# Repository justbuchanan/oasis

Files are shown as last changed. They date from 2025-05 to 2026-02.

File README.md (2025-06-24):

   

# Oasis

https://oasis-terrarium.com

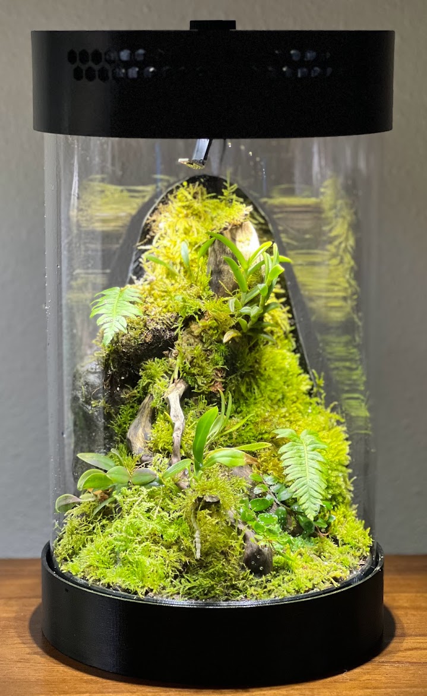
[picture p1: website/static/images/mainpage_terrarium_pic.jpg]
terrarium pic


Oasis is a fully open-source, mostly 3d-printed smart terrarium. It provides the ideal environment for humidity-loving plants like mosses, ferns, orchids, and many others. The design includes:

- [high power LED lighting](https://oasis-terrarium.com/docs/random_notes/#light-intensity)
- a mister for providing plants with water and maintaining high humidity
- fans for airflow
- a temperature/humidity sensor for monitoring environment conditions
- wifi connectivity to allow control and configuration from your phone or computer (see [web interface](https://oasis-terrarium.com/docs/usage_guide/#web-interface))
- outer dimensions: ~8" diameter and ~13" tall

See the website for pictures, build details and more: https://oasis-terrarium.com.

This repository contains full sources for the CAD models (designed with [CadQuery](https://github.com/cadquery/cadquery)), electronics (designed in [KiCad](https://www.kicad.org/)), and software (written in rust using the [esp-rs](https://github.com/esp-rs) libraries).

Most of this project is accessible to the average DIYer with access to a 3d printer, however the electronics portion of the project is a bit more involved. Fully-assembled electronics can be ordered from companies like JLCPCB by uploading the files from this repo, but this can be expensive for small order quantities. Those with the right equipment and experience soldering small parts could order the bare PCBs and components separately, then do their own assembly and soldering.

I'd like to eventually offer the assembled electronics as a kit, but don't have immediate plans for doing so. To express interest in a kit and to subscribe for future updates, please fill out this form: https://forms.gle/WesLJEf8hVrUT4jXA.

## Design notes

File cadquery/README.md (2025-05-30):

# CAD

The 3d-printed models for this project are designed with [CadQuery](https://github.com/CadQuery/cadquery).

See [CQ-editor's installation instructions](https://github.com/CadQuery/CQ-editor/wiki/Installation).

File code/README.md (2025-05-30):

# Oasis Software

The software for this project is divided up into four subdirectories:

- esp32/ - the actual code that runs on the main control board of the terrarium.
- client/ - a command-line client program that runs on linux/macos/windows(?) for controlling the terrarium and querying its state.
- demoserver/ - a server program that runs on your computer (again linux/macos/windows(?)) that allows for developing/testing the web interface without requiring an esp32-based control board.
- terralib/ - shared code that is used by the above three programs.

## ESP32 code

> [!WARNING]
> It is possible to fry the mister circuit on this board by changing the firmware code. The mister circuit expects a ~110kHz 50% duty cycle signal from the esp32. If you instead turn it fully on, it will likely let out the magic smoke within just a few seconds.

### Initial setup

The initial project in the esp32/ directory was setup from a template:

`cargo generate esp-rs/esp-idf-template cargo`

If stuff needs updating, do one or all of the below:

```
rustup update nightly

cargo update

# manually update versions of packages by editing Cargo.toml
```

### Build a single binary

`cargo build --bin oasis` or `cargo build --bin blinky`

### Re-compile when something changes using cargo-watch

`cargo-watch -x 'build --bin oasis'`

### Run oasis program

`cd esp32 && cargo run --release --bin oasis`

### ESP32 OTA Flashing

As of 3/29/25, the oasis program is about 1.7M in size. The total flash size of the ESP32-C3 is 4M. For ota (over-the-air updates) to work, we have to have room for _two_ versions of the app plus the nvs partition (for wifi calibration data), data partition (oasis config file), and phy_init (RF Data, not sure?). Looks like unless we can significantly reduce the size of the oasis app binary, OTA is not an option - there just isn't enough room on the flash memory.

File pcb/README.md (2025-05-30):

# Oasis PCB Design

## KiCad Plugins

This project uses a plugin for laying out components. Some values are defined in /oasis_constants.py, then used in both the CAD model and the PCB layout.

### Component layout plugin

The plugin is located at https://github.com/justbuchanan/kicad_component_layout/blob/versionfix/component_layout_plugin.py and must be copied into Kicad's plugin directory in order to use it.

Usage:

- run pcb/{main, ledboard}/layout.py, which generates a layout.yaml output.

- In Kicad's pcb editor, click "Tools" -> "External Plugins" -> "Layout footprints from layout.yaml".

To edit placement of items, modify `oasis_constants.py` and/or `pcb/{main, ledboard}/layout.py`.

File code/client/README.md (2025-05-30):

# Command-line client

This program connects to the terrarium over the network and allows for:

- scanning for any/all terrariums on the network
- controlling the terrarium (lights, fan, mist)
- configuring the schedule and wifi login for the terrarium
- querying terrarium state

Run `client --help` for full and up-to-date details.

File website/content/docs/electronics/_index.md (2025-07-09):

+++
title = 'Electronics'
weight = 4
+++

# Electronics

## How to get them?

There are essentially three options for obtaining the electronics:

- Order bare PCBs (from OSH Park, JLCPCB, PCBWay) and parts (digikey, mouser, etc) and solder them yourself. This can be a good option if you have experience with SMD soldering.
- Order fully-assembled PCBs from JLCPCB. This can be a good option if you'd prefer not to solder the boards yourself, but it can be expensive for small order quantities.
- [Sign up to buy a kit](/docs/contact/#buying-a-kit) if/when they become available. I don't have any immediate or concrete plans to sell these, but will consider it if there's enough interest.

See the [PCB Ordering Guide](#pcb-ordering-guide) below for more info.

## Design

### Overview

The electronics have a few main tasks:

- power the lights and allow for brightness control ("dimming")
- turn the fans on/off
- drive the mister (this is a somewhat complicated resonant circuit)
- communicate with the temperature+humidity sensor
- wifi
- usb port for programming/debugging

### Microcontroller

Requirements:

- i2c for sensors ([sht30](https://www.digikey.com/en/products/detail/sensirion-ag/SHT30-DIS-B2-5KS/5872250))
- 1 pwm for LED driver
- 1 pwm for mist
- 1 gpio for fans
- wifi

While there are a quite a few microcontrollers that fit the requirements, they vary widely in size and cost. I selected the esp32 due its small size (smaller than a postage stamp), SMD footprint (can be soldered directly to a board), and low cost (~$3).

### LEDs + Driver

I chose [Cree XT-E LEDs](https://downloads.cree-led.com/files/ds/x/XLamp-XTE.pdf) as these are common in the aquarium and terrarium hobbies for building high power lighting and because I have prior experience with them.

A string of LEDs is best powered by a constant-current driver. There are a lot of options here, but I selected the [Meanwell LDD-700LS](https://www.digikey.com/en/products/detail/mean-well-usa-inc/LDD-700LS/7704762) due to its small SMD footprint, dimming control via pwm, and ease of use (no external components required). This driver can provide up to 700mA (hence the 700 in the name), but there are several variants that can provide more or less current.

I chose to go with five LEDs laid out in a circle at the top of the terrarium. The circular spacing gives a more even lighting to the enclosure than we'd get with one LED in the center or several bunched closely together. The choice of five LEDs was somewhat arbitrary.

Cree XT-E LEDs have a forward voltage a little under 3V when current is 700mA (see page 21 of the [datasheet](https://downloads.cree-led.com/files/ds/x/XLamp-XTE.pdf)). With five LEDs in series, this means we need a total voltage of ~15V across the LEDs. The driver input voltage must be around 2v higher than its output voltage, giving us a minimum of ~17v to power the driver.

### Mister

I'm using an ultrasonic mister to provide watering in the terrarium. These are small discs made of a metal+piezo material sandwich with very tiny (~4uM) holes in the center. By applying an alternating voltage across the terminals of the disc, we can cause it to vibrate and "chop up" water into tiny particles that descend into the enclosure. The closer we can drive the disc to its natural resonant frequency (commonly ~110kHz), the faster and more efficiently we can drive it.

I heavily relied on these articles when designing the resonant circuit for driving the mister:

- https://www.edn.com/ultrasonic-mist-maker/.
- https://www.instructables.com/Make-Your-Own-Super-Simple-Ultrasonic-Mist-Maker/

Essentially a mosfet is switched on and off very quickly (~110kHz) causing it to alternate between "charging up" an inductor and dumping that charge across the misting disc. The mosfet is connected to a mosfet gate driver, which receives the 110kHz signal from a pwm output on the microcontroller.

Some mist driver circuits use a dedicated square wave generating IC like a 555 timer to provide the 110kHz signal, however this design uses a pwm output from the microcontroller. This has a couple advantages:

- less components
- the signal frequency can be changed in software to accommodate different misting discs

And one key disadvantage: it is possible to write firmware that outputs an "always on" signal rather than the expected 110kHz square wave, which will cause the misting circuit to let out the magic smoke.

### Voltage Requirements

- LED driver: >17v
- sensors: 2.2v - 5.5v
- esp32: 3.3v
- fans: nominally 24v, but can run at 18v
- mist: >12v

I chose to use an input voltage supply of 18v in order to satisfy the requirements of the higher-voltage devices, then include a voltage regulator to provide 3.3v for the lower-voltage devices. I selected a buck converter from TI and used their WeBench tool to design a regulator circuit. See details [here](https://github.com/justbuchanan/oasis/blob/main/pcb/reference/voltage-circuit-export-from-ti-webench.pdf).

### Thermal Considerations

It turns out that LEDs, even fairly efficient ones like we're using here, produce a lot of heat.

The initial design of the electronics placed all components, including the LEDs and the temperature+humidity sensor on one board. I anticipated that this might have issues with overheating, but the elegance of having everything on one board was too hard to resist, so I stubbornly pushed forward. Below are renders of the initial design:

<!-- Show the front and back renders side-by-side -->
<div class="img-row">
  <div class="img-column2">
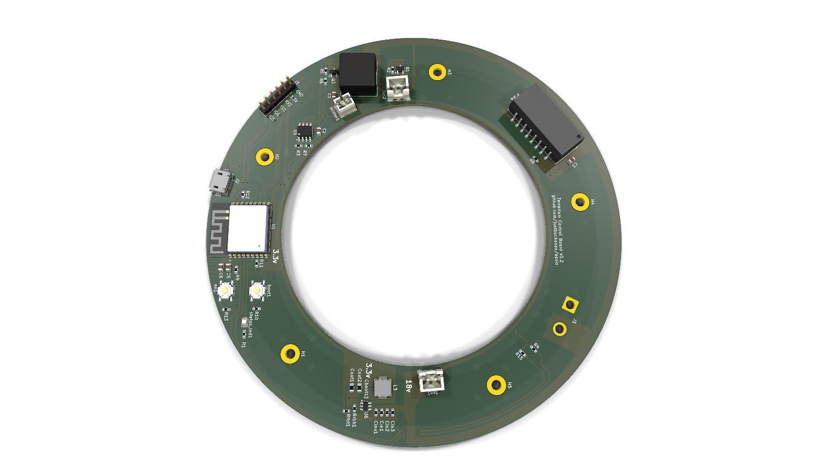
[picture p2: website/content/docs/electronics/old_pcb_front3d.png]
    
    <p>Top View</p>
  </div>
  <div class="img-column2">
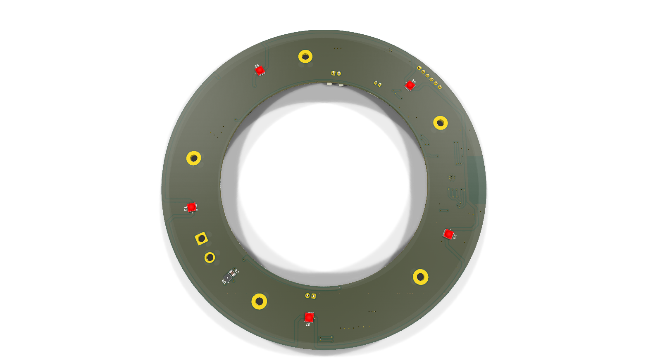
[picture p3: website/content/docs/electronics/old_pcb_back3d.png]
    
    <p>Bottom View</p>
  </div>
</div>

Predictably, the LEDs quickly caused the board to heat up, throwing off the temperature sensor readings and bringing the esp32 close to its operating limits. I attempted to mitigate the overheating by drilling lots of ventilation holes in the 3d-printed top of the enclosure and sticking a dozen small heat sinks to the top of the circuit board. This helped a bit, but not enough. The only way to make this work would be to significantly limit the max LED brightness in firmware, leaving the lighting levels significantly below what I had hoped for the terrarium.

Back to the drawing board! The final design opts to place the LEDs on their own board made out of aluminum to act as a heat sink. Almost everything else is placed on a separate mainboard. The temperature+humidity sensor is on its own board that sits inside the enclosure, thermally isolating it from the heat of the LEDs.

## Mainboard

The mainboard contains:

- a microcontroller with builtin wifi ([esp32-c3](https://www.espressif.com/en/products/socs/esp32-c3))
- led driver
- 18v to 3.3v voltage converter
- ultrasonic mister driver
- fan driver
- usb connector for updating firmware

Find the KiCad design files here: https://github.com/justbuchanan/oasis/tree/main/pcb/main.

### Schematic

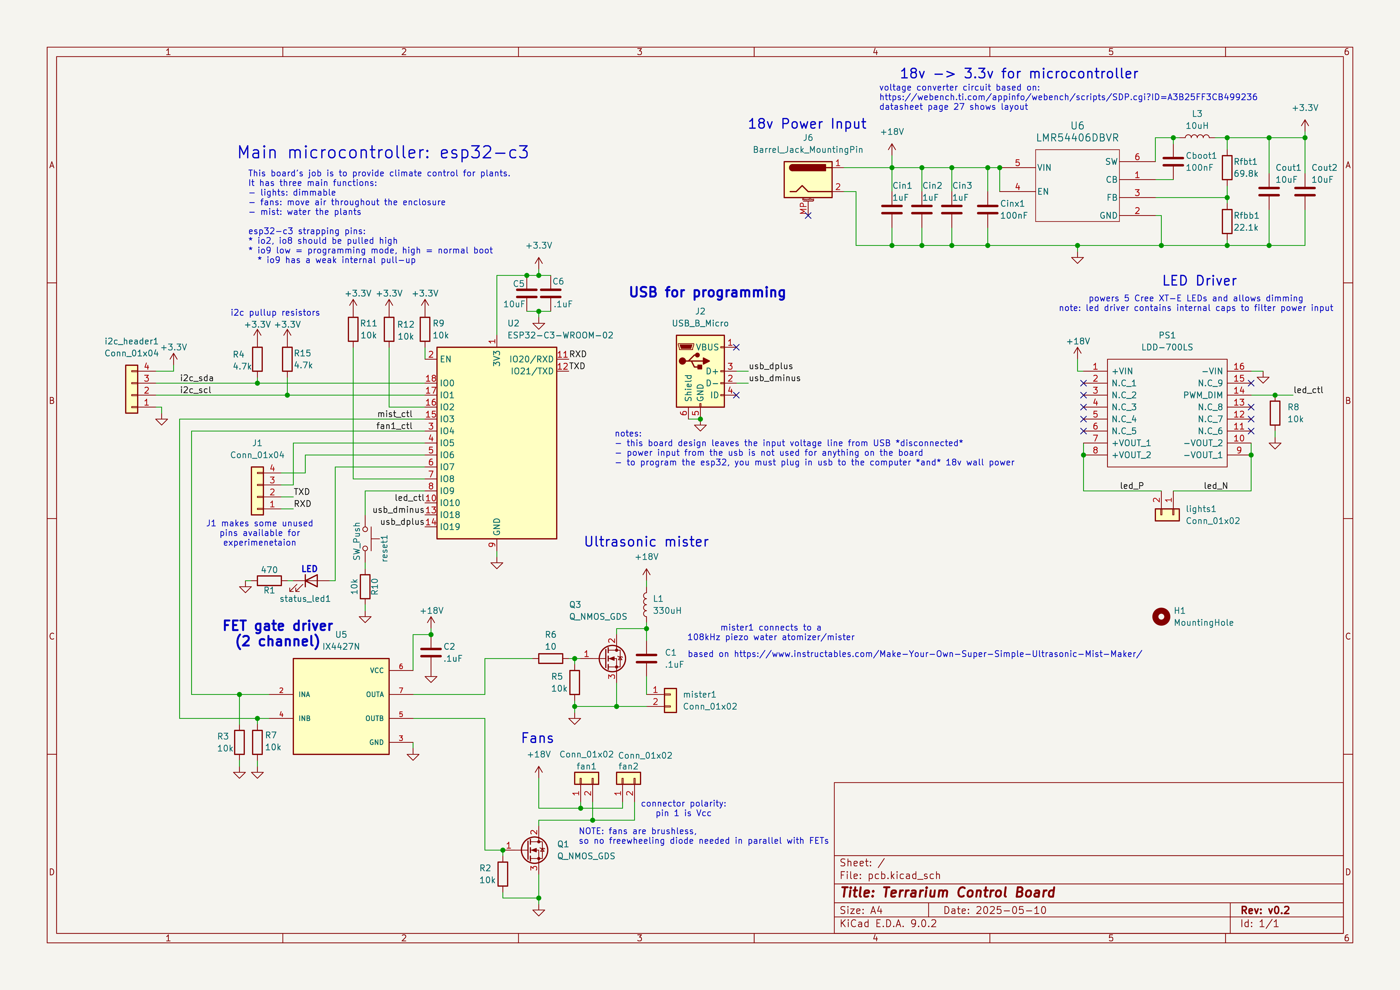
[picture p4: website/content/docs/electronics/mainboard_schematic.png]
schematic


### 3D Renders

<!-- Show the front and back renders side-by-side -->
<div class="img-row">
  <div class="img-column2">
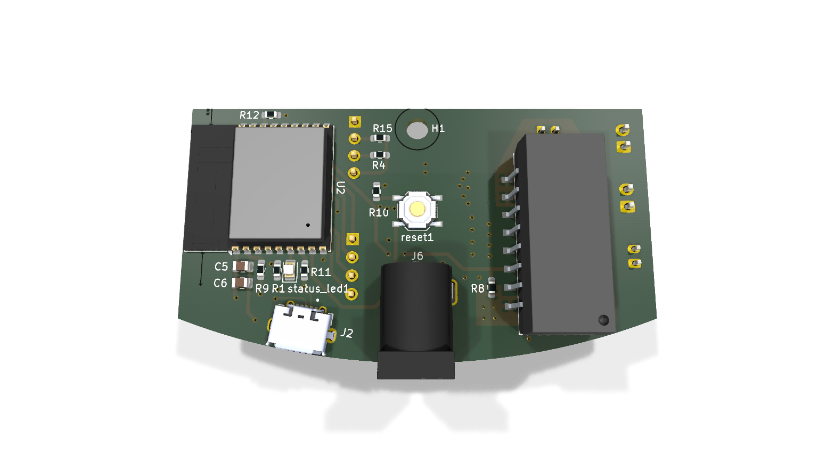
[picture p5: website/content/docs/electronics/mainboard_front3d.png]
    
    <p>Top View</p>
  </div>
  <div class="img-column2">
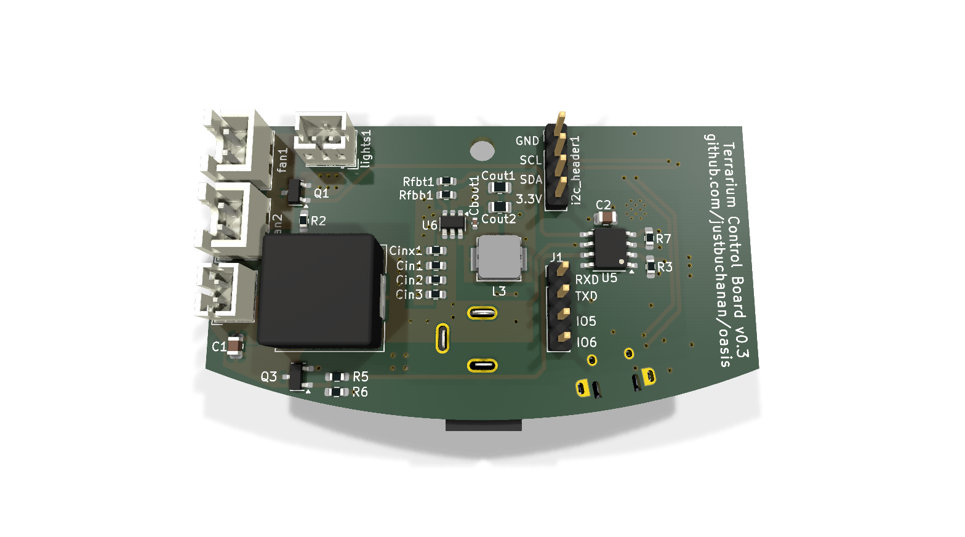
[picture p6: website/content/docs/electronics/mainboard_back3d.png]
    
    <p>Bottom View</p>
  </div>
</div>

## Ledboard

The LED board is very simple - it's 5 LEDs wired in series mounted on an aluminum board to act as a heatsink.

Find the KiCad design files here: https://github.com/justbuchanan/oasis/tree/main/pcb/ledboard.

In order to connect to the mainboard, the ledboard needs a 2-pin JST PH connector (for example https://www.amazon.com/dp/B01DUC1O68) soldered onto it.

### Schematic

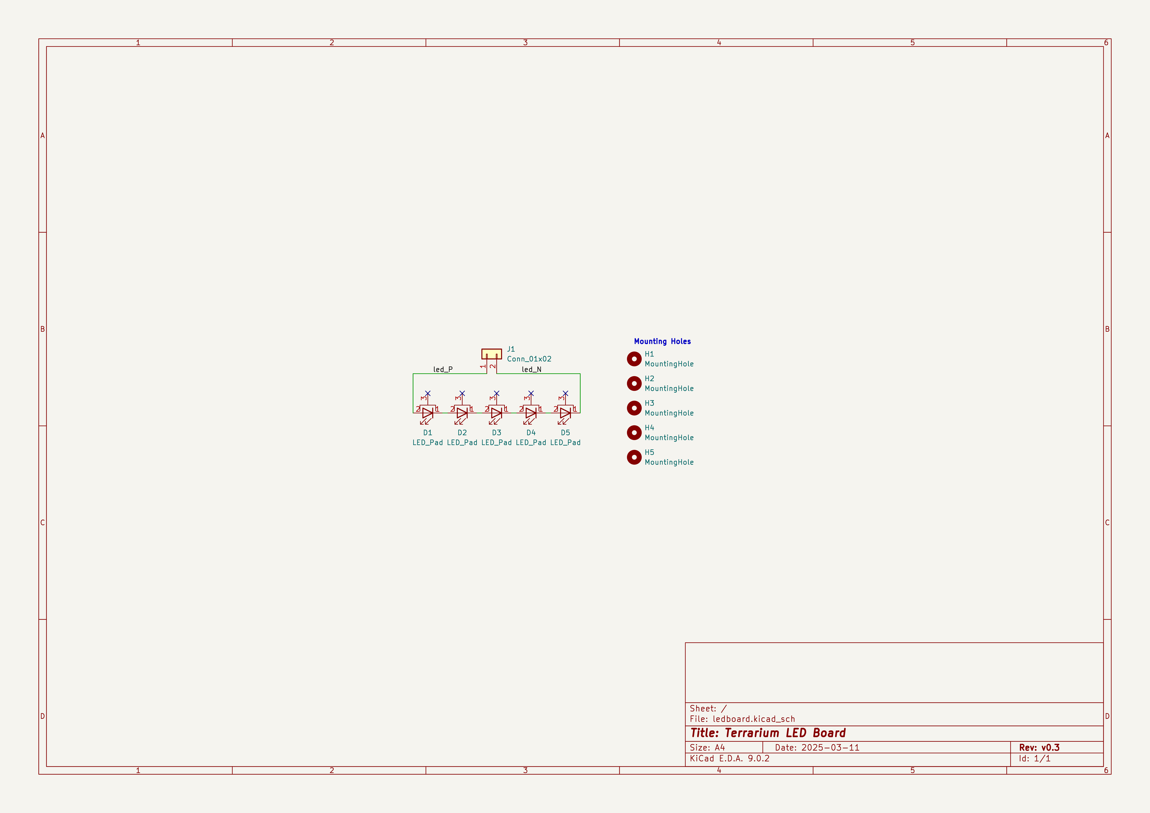
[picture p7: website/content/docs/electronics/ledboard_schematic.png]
schematic


### 3D Render

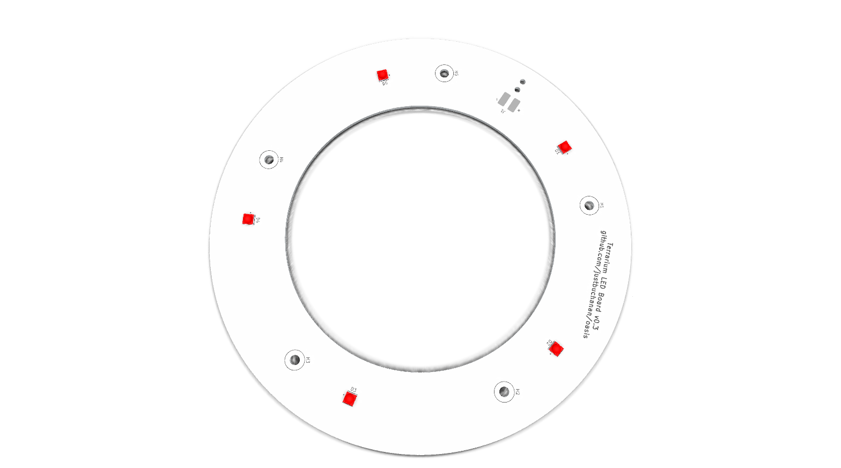
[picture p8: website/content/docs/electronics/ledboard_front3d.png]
front


## SHT30 Sensor Board Wiring

The sht30 sensor board comes without a cable. You'll need to solder a standard 4-pin connector cable in order to plug it into the mainboard.

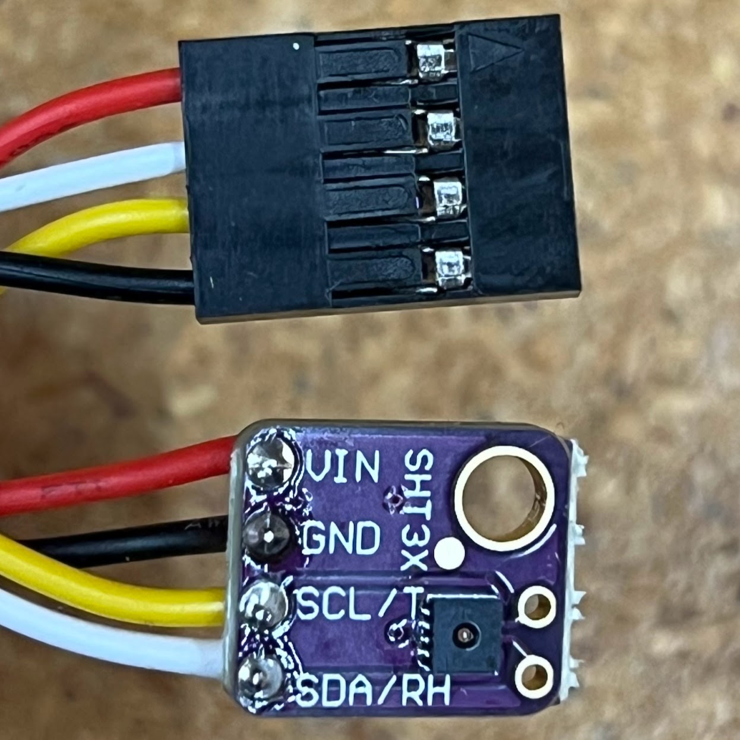
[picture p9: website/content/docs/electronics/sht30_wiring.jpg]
sht30_wiring


## PCB Ordering Guide

There are a lot of options for custom PCB manufacturing. I chose to go with JLCPCB due to low cost, support for board assembly, and extensive component catalog. PCBWay is another good option that also provides assembly services. OSH Park is a good choice for US-based manufacturing, but they don't offer assembly services.

### PCB Production Files

To order custom PCBs, you'll need the production files to send to the manufacturer. If you're ordering bare/un-assembled boards, you'll just need the [gerber files](https://en.wikipedia.org/wiki/Gerber_format) (typically bundled into a `gerbers.zip`), which are essentially vector image files that specify things like where copper traces are located on either side of the board, silkscreen text and images on either side of the board, etc.

If you're looking to order assembled boards, you'll additionally need two more files:

- `bom.csv`: a bill of materials file, which maps from component ids in the board design to specific part numbers in the manufacturer's part catalog
- `pos.csv`/`positions.csv`: file which records the location and orientation of each part

All three production files are generated from the KiCad design files using the [Fabrication-Toolkit plugin](https://github.com/bennymeg/Fabrication-Toolkit). This plugin can be invoked from the KiCad user interface or from the command line. The command line invocation for the plugin is contained in this project's [makefile](https://github.com/justbuchanan/oasis/blob/fbd0d2fceae36f7a195ebd945a816dcebf819d9c/makefile#L142-L147), which you can run with `make pcb`. This will generate the production files for both boards in `build/pcb/main` and `build/pcb/ledboard`. If you make modifications to the board in the KiCad Schematic Editor, run "Tools -> Update PCB From Schematic", then rerun `make pcb` to regenerate the files.

While you can check out the `main` branch of the project in git and use the KiCad files directly, it is recommended to use a tagged release which has been vetted for correctness. It's possible that as the project evolves, changes will be made to the KiCad files that haven't yet been tested.

Tagged releases can be found on the project's [Releases Page on GitHub](https://github.com/justbuchanan/oasis/releases). Alternatively, you can use the design files in the [pcb/fabricated-boards](https://github.com/justbuchanan/oasis/tree/main/pcb/fabricated-boards) directory, which is an archive of all boards ordered to-date.

### Notes On Assembly and Component Selection

JLCPCB has an extensive [catalog of parts](https://jlcpcb.com/parts) they stock in their warehouse(s) and many of the components selected for this project were specifically chosen based on their availability at JLCPCB. There are a couple parts in this design that JLCPCB doesn't stock (including the LED Driver and LEDs) and need to be handled separately. Furthermore, the parts inventory is constantly in flux and it's possible that certain parts that were in stock previously are not in stock when you're placing an order. There are a few options here:

- Skip assembly of those parts, order them separately from somewhere like digikey, then solder them yourself at home.
- Use JLCPCB's pre-order service, which allows you to order almost any part from another supplier. It will take a week or two for the parts to arrive at JLCPCB, after which point you can submit your board order.
- Select a different/equivalent part from JLCPCB's catalog that they do have in stock. This will require you updating the "LCSC Part #" field of the relevant component in KiCad, then regenerating and re-uploading the `bom.csv` file.

#### Overhead Costs and "Basic" vs "Extended" Parts

JLCPCB uses large [pick-and-place machines](https://en.wikipedia.org/wiki/Pick-and-place_machine) for board assembly. These machines have a number of component "reels" attached to them, which hold things like resistors, capacitors, connectors, etc. For commonly-used parts, such as a 1k 0805 resistor, JLCPCB has selected a specific model of the part that they keep loaded up in each of their machines. JLCPCB calls these "Basic Parts" and charges no assembly fee for them since they're already loaded into every machine. When selecting parts, try and find a "Basic" part that fits the bill in order to save money. Any non-"Basic" (i.e. "Extended") parts that require assembly will cost you a $3 setup fee per part. If you're ordering a large number of boards, this is a small cost. If you're only ordering a few, these assembly costs add up.

### JLCPCB Ordering Step-by-Step

Below is a step-by-step guide to placing a board order through JLCPCB. This will focus on the main board, but the steps are largely the same for the LED board. The main differences with the LED board are that the board should be made of aluminum (to act as a heat sink) instead of the standard FR4 and that only one side of the board requires assembly.

1. Go to https://jlcpcb.com and login
1. Upload gerbers.zip
1. (optional) select quantity - default is 5
1. (optional) "Surface Finish": select "LeadFree HASL". Costs like $4 extra on a 5-board order, so why not skip the lead.
1. If you're just ordering bare PCBs, you're done! Finish up the checkout process and place your order.
1. Toggle "PCB Assembly" ON
1. To assembly both sides of the mainboard, change "PCBA Type" from "Economic" to "Standard", then change "Assembly Side" to "Both Sides"
1. (optional) Enable "Confirm Parts Placement" and "Confirm Production file" - it's cheap, so why not have them double-check things?
1. (optional) Adjust assembly quantity. Default is 5, but you could for example order 5 total boards and have only 2 of them assembled.
1. Click the "Next" button
1. Take a quick look over the board images, then click "Next" again
1. Upload "bom.csv" and "positions.csv", then click the "Process" button
1. You're now presented with the bill of materials. If any of the parts say "shortfall" in the right-most column, it means JLCPCB doesn't have those parts. See [Notes on Assembly and Component Selection](#notes-on-assembly-and-component-selection) above.
1. Click "Next" to move on to the assembly review page
1. Click "Next" to move on to the "Quote & Order" Page.
1. Select a "Product Description" from the dropdown. This has tax/tariff/legal implications, but probably doesn't matter much for us. I've been selecting "Other" and typing in "Terrarium for Plants".
1. "Save to Cart" and continue on to checkout
1. See if you can find any relevant coupons: https://jlcpcb.com/coupon-center. There's likely a $15 off coupon for SMT orders over $150. Maybe also a new customer coupon.
1. Finish the checkout process

## PCB Order History

Below are all three circuit board orders I've placed for this project (as of June 2025). All boards were ordered from JLCPCB and include varying levels of assembly (components sourced and soldered by JLCPCB).

### v0.1 all-in-one board - Feb 11, 2025

Single-board design - esp32, leds, sht30 temp/humid sensor, and everything else all on one board.

A lot of the board was assembled by JLC, but the following parts were purchased and assembled separately (in total, probably $17 worth of parts per board):

- led driver
- leds
- sht30 temp/humid sensor
- sht30 bypass capacitor

Files: https://github.com/justbuchanan/oasis/tree/main/pcb/fabricated-boards/v0.2

#### Pricing

note: this price info is what I was charged by JLC, it does not include the components I sourced and assembled myself (mentioned above).

- total: $140
    - merchandise total: $89
    - shipping: $38
    - sales tax: $13

This order was for five boards, so price/board was $28 + ~$17 = ~$45.

### v0.2 ledboard - March 16, 2025

Based on the poor thermal performance of the all-in-one boards, I decided to do a major redesign and put the leds on their own board, made out of solid aluminum. The rest of the electronics are on their own board.

This order is for 5x 1.6mm thick aluminum boards for the leds. Price/board = $6.84. This price doesn't include the 5 Cree XT-E LEDs or the connector cable soldered on.

Files: https://github.com/justbuchanan/oasis/tree/main/pcb/fabricated-boards/ledboard-v0.3

#### Pricing

- total: $35
    - merchandise total: $14
    - shipping: $18
    - sales tax: $3

### v0.2 mainboard - March 21, 2025

Files: https://github.com/justbuchanan/oasis/tree/main/pcb/fabricated-boards/mainboard-v0.3

5 Control boards. Fully assembled except the 2 4-pin headers. Price/board = $40.6.

- total: $203
    - merchandise total: $153
    - shipping: $29
    - sales tax: $21

## Power Consumption

Power consumption of the electronics was measured using a bench power supply set to 18V. Here are the results:

| Configuration | Current Draw (amps) |
| --- | --- |
| Microcontroller plugged in, everything (mist, fans, lights) off | 0.01-0.03 |
| LEDs 100% on | 0.61 |
| Fans on | 0.09 |
| Mister on, water present | 0.05 |
| Mister on, no water present | 0.03 |
| Everything on (mister, fans, LEDs @ 100%), water present | 0.72 |

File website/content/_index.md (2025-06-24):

+++
title = 'About'
weight = 1
+++

# Oasis

Oasis is a fully open-source, mostly 3d-printed smart terrarium.

{{< video src="docs/video.mp4" width=100% controls="yes" autoplay="true" >}}

Features include:

- [high-power LED lighting](/docs/random_notes/#light-intensity)
- a built-in water tank and mister to provide plants with water and maintain high humidity
- fans for airflow
- a temperature+humidity sensor for monitoring environment conditions
- wifi connectivity to allow control and configuration from your phone or computer (see [web interface](/docs/usage_guide/#web-interface))
- outer dimensions: ~8" diameter and ~13" tall

This project is fully open-source, meaning that the designs for the 3d printed parts, electronics schematics, and software are available to download and modify. Find them on GitHub: https://github.com/justbuchanan/oasis.

This website contains a detailed [build guide](/docs/build_guide), bill of materials, and other notes on the project.

Most of this project is accessible to the average DIYer with access to a 3d printer, however the electronics portion of the project is a bit more involved. See the [Electronics page](/docs/electronics) for more details.

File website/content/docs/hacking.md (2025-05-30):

+++
title = 'Hacking'
weight = 6
+++

# Hacking

This is an open-source project built on open-source tools. It uses [KiCad](https://www.kicad.org/) for electronics design, [CadQuery](https://github.com/CadQuery/cadquery) for 3d-modeling, and [rust](https://www.rust-lang.org/) for the software.

## Code

See the readme for more info: https://github.com/justbuchanan/oasis/blob/main/code/README.md

## CAD models

The CAD models for this project are designed in [CadQuery](https://github.com/cadquery/cadquery), which uses python for part design. This project's [requirements.txt file](https://github.com/justbuchanan/oasis/blob/main/requirements.txt) contains the relevant python dependencies, but you may need to consult the CadQuery documentation for further installation instructions.

Note that while the python environment is _mostly_ for working with the CAD models, there are some optional python dependencies needed for working with the KiCad electronics designs. These include the [Fabrication-Toolkit plugin](https://github.com/bennymeg/Fabrication-Toolkit) for exporting manufacturing files for JLC PCB and the [component layout plugin](https://github.com/justbuchanan/kicad_component_layout).

### Python Environment Setup

#### Initial setup (do once)

```sh
cd <this project>
mkdir -p pyvenv
python -m venv ./pyvenv --system-site-packages
source ./pyvenv/bin/activate
pip install -r requirements.txt
```

#### Environment (do every time)

Run this in your shell before you do anything related to python, including running `make`.

```sh
cd <this project>
source ./pyvenv/bin/activate
```

## Command-Line Client

This project comes with a command-line client that can:

- configure wifi credentials
- set the terrarium's schedule (lights, fans, mister)
- query the terrarium's state (sensors, light level, etc)
- control lights, fans, mister
- scan the network for online terrariums

Source code is at https://github.com/justbuchanan/oasis/tree/main/code/client.

For full documentation, build the client and run `oasis --help`.

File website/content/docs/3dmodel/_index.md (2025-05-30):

+++
title = '3D Model'
weight = 5
+++

<script type="module" src="https://ajax.googleapis.com/ajax/libs/model-viewer/4.0.0/model-viewer.min.js"></script>

<model-viewer id="model"
              src="oasis.glb"
              alt="Oasis Terrarium 3D Model"
              field-of-view="8deg"
              camera-orbit="90deg"
              camera-controls
              touch-action='pan-y'
              ar
              style="width: 100%; height: 1000px;">
</model-viewer>

Controls:

- Scroll to zoom
- left-click drag to rotate
- right-click drag to pan

<script>
const modelViewer = document.getElementById('model');

modelViewer.addEventListener('load', () => {
    console.log("played");
  modelViewer.play({repetitions: 1});
});
</script>

<!-- Creating the glb file:
1. export from cadquery by running `make build/cadquery/oasis.glb`
2. open blender
3. import oasis.glb
4. Follow this youtube video to create the exploding effect: https://www.youtube.com/watch?v=IC0-9b0Rv2g&ab_channel=GeorgeKayesi
    4.1. create an empty shape (cube or axes) and move it off to the side of the terrarium model. Scale up the cube a bit (maybe 50x) to make it easily visible. Set its z position to zero - that way it's easy to get it back to its start position later.
    4.2. select the tube/walls, then add a "copy position" constraint.
        - only z axis should be applied (uncheck x and 7)
        - check the "offset" box
    4.3. select every shape that isn't the tube/walls. then select the walls (this must be selected last). then copy the "copy position" constraint to selected objects.
        - note: don't select visually and don't select them direct in the tree view on the right side. you need to individually select each part (an extra level deep in the tree, has an upside-down triangle next to it)
5. drag the empty cube upwards until the top-most item in the assembly is where you want it to be.
6. for every part, adjust the copy position influence down so the part is where you want it.
6. TODO: figure out keyframe 1 and keyframe 100
7. export the finished product. this is mostly just the same glb as before, but with an added animation.
    - animation checkbox: checked
    - animation mode: active actions merged
        - note that the default options export a separate animation for each individual object in the assembly. model-viewer works best (or at all?) with one single animation.
        - bake animations box: checked

Glass:
On the right side, click the "Render Properties" Menu
    - Render Engine: set to "Cycles"

Click on acrylic walls, then go to material menu
- Use Principled BSDF
- color should be white
- set Roughness to 0
- IOR set to 1.45
- Transmission: set to 1.0 (or maybe just a hair less?)

Plastic material:
    - Roughness factor: 1.0 -> 0.75
    - metallic factor: 1.0 -> 0.5
 -->

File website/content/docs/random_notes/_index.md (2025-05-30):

+++
title = 'Random Notes'
weight = 7
+++

# Random Notes

## Light Intensity

I used the [Photone App for iOS](https://apps.apple.com/us/app/photone-grow-light-meter/id1450079523) to take some lighting measurements. An actual PAR meter would give more accurate measurements, but those are expensive and I already spent all my money on tariffs importing custom electronics from China.

These measurements were taken with an iPhone sitting at the _bottom_ of the terrarium. You will get higher PAR values higher up in the enclosure.

The LEDs are powerful and, due to thermal considerations, the LED driver is limited to 80% power in the firmware (see code [here](https://github.com/justbuchanan/oasis/blob/main/code/esp32/src/terrarium/real_terrarium.rs)). The below percentage values are what you would set in the terrarium's control interface, so for example, the 80% value below actually means 80%\*80%=64% of what the LEDs/driver are capable of.

This test was done with CREE XT-E 5700k LEDs. Results may vary for different color temperatures.

| Light % | PAR (umol/m^2/s) |
| --- | --- |
| 80% | 325 |
| 100% | 414 |

### How much light do plants want?

Here are a couple pages I found helpful:

- https://www.neherpetoculture.com/vivariumlighting101
- https://herebutnot.com/light-recommendations-ppfd-par-for-orchids-and-houseplants/

tl;dr: these LEDs are very bright, don't set them too high.

## Ideas for Future Improvement

The terrarium in its current state works well, but there's room for improvement. Below are a few ideas for a future version of the design:

- The terrarium should be able to detect when the water tank is empty. There are a few options for how to implement this:
    - Add a sensor inside the tank. A float sensor or capacitive sensor could work well.
    - Measure mister current draw. The mister circuit draws almost 2x as much current when water is present.
    - Measure humidity before and after running the mister and see if it increased. It should be possible to do this in software using the current hardware, but can be tricky.
- Increase airflow from fans. While the fans are not particularly powerful to begin with, they are somewhat limited in the current design by the size of the inflow and outflow paths built into the 3d printed parts. This is in turn limited by the size of the led board. If the led board is made smaller in a future version, there could be room to make the air inlet larger.
- The mister/mount/screws stick out below the bottom of the Top. Ideally, the top should be able to set down (face down) on a table and not have anything touch.
- The cord running down the back is ugly. I don't really see a way around this, but adding a cable clip to the bottom piece might help at least tidy it up a bit.
- Make the water tank bigger. Right now there's some "wasted" space that could be used to have the terrarium hold more water.

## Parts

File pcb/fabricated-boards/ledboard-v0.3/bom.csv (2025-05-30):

Designator | Footprint | Quantity | Value | LCSC Part #
D1, D2, D3, D4, D5 | LED_XTEAWT-00-0000-000000F51 | 5 | LED_Pad | C9900048586
J1 | wire2board_smt_justin | 1 | Conn_01x02 | C295747

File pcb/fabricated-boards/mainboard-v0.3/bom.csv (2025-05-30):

Designator | Footprint | Quantity | Value | LCSC Part #
C1, C2, C6 | 0805 | 3 | .1uF | C28233
C5 | 0805 | 1 | 10uF | C15850
CBOOT1 | 0402 | 1 | 100nF | C1525
CIN1, CIN2, CIN3 | 0603 | 3 | 1uF | C15849
CINX1 | 0603 | 1 | 100nF | C14663
COUT1, COUT2 | 0805 | 2 | 10uF | C440198
FAN1, FAN2 | JST_XH_B2B-XH-A_1x02_P2.50mm_Vertical | 2 | Conn_01x02 | C158012
I2C_HEADER1, J1 | PinHeader_1x04_P2.54mm_Vertical | 2 | Conn_01x04
J2 | MOLEX_47590-0001 | 1 | USB_B_Micro | C136001
J6 | DC-IN-TH_XDJK-0051-025_JLC_C7498153 | 1 | Barrel_Jack_MountingPin | C7498153
L1 | L_SXN_SMDRI127 | 1 | 330uH | C10152
L3 | L_Vishay_IHLP-2020 | 1 | 10uH | C844983
LIGHTS1, MISTER1 | JST_PH_B2B-PH-K_1x02_P2.00mm_Vertical | 2 | Conn_01x02 | C131337
PS1 | LDD-700LS-SOP254P1280X930-16N | 1 | LDD-700LS | C17353291
Q1, Q3 | SOT-23-3-pinswapped-mosfet | 2 | Q_NMOS_GDS | C7420571
R1 | 0603 | 1 | 470 | C23179
R10, R11, R12, R2, R3, R5, R7, R8, R9 | 0603 | 9 | 10k | C25804
R15, R4 | 0603 | 2 | 4.7k | C23162
R6 | 0603 | 1 | 10 | C22859
RESET1 | SW_Push_1P1T_XKB_TS-1187A | 1 | SW_Push | C318884
RFBB1 | 0603 | 1 | 22.1k | C844759
RFBT1 | 0603 | 1 | 69.8k | C861526
STATUS_LED1 | 0805 | 1 | LED | C2297
U2 | ESP32-C3-WROOM-02 | 1 | ESP32-C3-WROOM-02
U5 | SOIC-8-1EP_3.9x4.9mm_P1.27mm_EP2.29x3mm | 1 | IX4427N | C171845
U6 | SOT-23-6 | 1 | LMR54406DBVR | C3193129

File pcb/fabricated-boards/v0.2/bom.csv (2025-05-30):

Designator | Footprint | Quantity | Value | LCSC Part #
BOOT1, EN1 | SW_Push_1P1T_XKB_TS-1187A | 2 | SW_Push | C318884
C1, C2, C3, C4, C6 | 0805 | 5 | .1uF | C28233
C5 | 0805 | 1 | 10uF | C15850
CBOOT1 | 0402 | 1 | 100nF | C1525
CIN1, CIN2, CIN3 | 0603 | 3 | 1uF | C15849
CINX1 | 0603 | 1 | 100nF | C14663
COUT1, COUT2 | 0805 | 2 | 10uF | C440198
D1, D2, D3, D4, D5 | LED_XTEAWT-00-0000-000000F51 | 5 | LED_Pad
FAN1, FAN2 | JST_XH_B2B-XH-A_1x02_P2.50mm_Vertical | 2 | Conn_01x02 | C158012
J2 | USB_Micro-B_Amphenol_10104110_Horizontal | 1 | USB_B_Micro | C428496
J3 | PinHeader_1x06_P2.54mm_Vertical | 1 | Conn_01x06 | C7430362
L1 | L_SXN_SMDRI127 | 1 | 330uH | C10152
L3 | L_Vishay_IHLP-2020 | 1 | 10uH | C844983
MISTER1 | JST_PH_B2B-PH-K_1x02_P2.00mm_Vertical | 1 | Conn_01x02 | C5251182
PS1 | LDD-700LS-SOP254P1280X930-16N | 1 | LDD-700LS | C17353291
Q1, Q3 | SOT-23-3 | 2 | Q_NMOS_GDS | C7420571
R1 | 0603 | 1 | 470 | C23179
R10, R11, R12, R2, R3, R5, R7, R8, R9 | 0603 | 9 | 10k | C25804
R13 | 0603 | 1 | 1k | C21190
R15, R4 | 0603 | 2 | 4.7k | C23162
R6 | 0603 | 1 | 10 | C22859
RFBB1 | 0603 | 1 | 22.1k | C844504
RFBT1 | 0603 | 1 | 69.8k | C137689
STATUS_LED1 | 0805 | 1 | LED | C2297
U1 | MODULE_ESP32-C3-WROOM-02-H4 | 1 | ESP32-C3-WROOM-02-N4 | C2934560
U4 | Sensirion_DFN-8-1EP_2.5x2.5mm_P0.5mm_EP1.1x1.7mm | 1 | SHT30-DIS | C77361
U5 | SOIC-8-1EP_3.9x4.9mm_P1.27mm_EP2.29x3mm | 1 | IX4427N | C171845
U6 | SOT-23-6 | 1 | LMR54406DBVR | C5219316

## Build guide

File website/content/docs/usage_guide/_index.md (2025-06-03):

+++
title = 'Usage Guide'
weight = 3
+++

# Usage Guide

You're terrarium's all assembled, what's next?

## A Note on WiFi / Internet Access

The terrarium is designed to connect to your home wifi network for two reasons.

The most obvious is so that it can be configured, controlled, and monitored from your phone or computer.

The less obvious reason is that the terrarium has no way of knowing what time it is when it first turns on. In order to determine the current time, it asks the internet (see [ntp on wikipedia](https://en.wikipedia.org/wiki/Network_Time_Protocol)). This is the only communication the terrarium does with the internet. If you're familiar with software, you're welcome to review the [code](https://github.com/justbuchanan/oasis/tree/main/code) and verify for yourself :)

> [!NOTE]+ Note
> It would be possible to change the software so that you can manually tell the terrarium what time it is, making it unnecessary for it to connect to the internet. The downside is that you would have to do this every time you unplug it or there's a power outage.

> [!NOTE]+ Note
> It would be possible to add a battery and a time-keeping circuit to the control board so that once configured, the terrarium wouldn't need to use the internet to determine the current time. The downside is that this would increase the cost and complexity of the device. Because WiFi connectivity is already required to control the terrarium from your phone/computer, this probably isn't worth it.

## Firmware Installation / Updates

Before you can begin using the terrarium, you'll need to install the firmware on the mainboard. See the [readme](https://github.com/justbuchanan/oasis/tree/main/code#run-oasis-program) for more info.

## Initial Setup

After plugging in the power supply, Oasis will start up and begin broadcasting its own wifi network named something like `oasis-1234` (with a random 4-digit number). Connect to this network, then open your web browser and navigate to `http://oasis.local` to connect to the terrarium.

In the "Settings" section at the bottom, you can enter the name and password for your wifi network and optionally change the "hostname" of the terrarium. The default hostname makes the terrarium accessible at "http://oasis.local", but you can change it to whatever (valid) name you'd like. Once you've entered the wifi information, click the "submit" button. This will cause the terrarium to restart and attempt to connect to your wifi network.

You can now connect your phone/computer back to your main wifi network and browse to the hostname of the terrarium (again the default is "http://oasis.local"). Assuming everything worked, you're all setup!

If the terrarium was unable to connect to the network, it will revert back to broadcasting its own network (something like "oasis-1234"), allowing you to re-enter the wifi password, etc, and try again.

## Web Interface

Here's a screenshot:

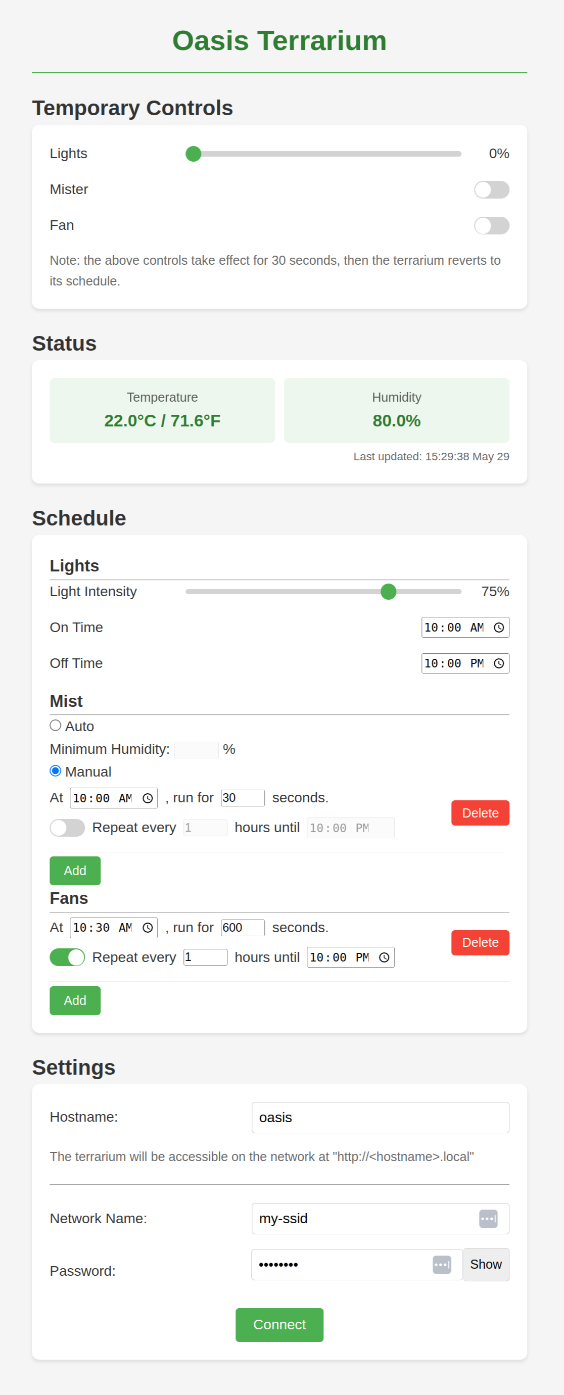
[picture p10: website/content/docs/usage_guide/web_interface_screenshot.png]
web_interface_screenshot


### Schedule

Oasis defaults to having the lights on at 70% power from 10am to 10pm, but you can adjust this however you'd like based on your selection of plants and personal preferences.

> [!NOTE]
> The LED lighting in this design is fairly powerful and it's likely that 100% power is too high for many plants. You may need to experiment to determine what the light intensity should be for your setup.

Like the lighting, the mister and fans can be scheduled to run throughout the day.

### Temporary Controls

In addition to the automated schedule, the lights, mister, and fans can be controlled on a temporary basis using the controls at the top of the web interface.

From past experience, I've learned that it's not a good idea to have a button that says "turn the mist on until I turn it off again" because at some point you will press the button and walk away and forget about it. When you return later, the water tank will be empty and your plants will be drenched. For this reason, the temporary controls all take effect for 30 seconds, before reverting back to the terrarium's configured schedule.

## Filling the Water Tank

To access the water tank, unscrew the plug on the top. Fill the tank until the water level is just a bit below the o-ring. I'd recommend using a funnel or a squirt bottle (something like [this](https://www.amazon.com/dp/B07DB1HCKP)) to fill the tank because otherwise it is very easy to spill water through the ventilation holes into the top piece of the terrarium. Perhaps having the ventilation holes so close to the water fillup port is a design flaw, but this is the current state of the design.

### Distilled or RO Water is Recommended

## Adjusting the Mister

too tight = reduced mist output
too loose = water leaking around the o-ring/mister

## Plants!

I'll refrain from including much information on design and planting here because there are a lot of good resources online that cover this in depth.

When it comes to plants, the main thing to keep in mind is that the terrarium is a high-humidity environment. Plants like succulents and cacti will not do well here. Plants like mosses, ferns, miniature orchids, and many others will do well.

Another consideration is size - select plants that won't quickly outgrow the limited space available.

By design, the side walls of the terrarium are easy to remove and put back again. This makes it easy to clean the walls and to get access to your plants for trimming, rearranging, etc. You may opt to build your terrarium in a way that the walls will stay fixed - maybe you want to lean sticks, rocks, dirt, etc against the walls to create a structured layout, and that's ok! Just be aware that you may be unable to remove the walls later. If you go this route, consider glueing the walls into the bottom piece for added strength.

## Hard Reset

The terrarium includes a hard reset button at the top that can be pressed using a standard paperclip. You should never actually have to use this - it's there as a failsafe in case there's an issue with the software and you want to reset the configuration to "factory default".

If you're having issues with connecting to the terrarium, first try rebooting it. There is no reboot button - just unplug the power cable, then plug it back in.

If you do need to use the hard reset, press the button down for ~5 seconds. The terrarium will start flashing its lights slowly for those 5 seconds, then flash them quickly to let you know the reset was registered. It will then delete its configuration (wifi information, schedule, etc) and reboot. Once it restarts, you can follow the [Initial Setup](#initial-setup) instructions to reconfigure it.

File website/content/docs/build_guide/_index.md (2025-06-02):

+++
title = 'Build Guide'
weight = 2
+++

# Oasis Build Guide

Below is a step-by-step guide on building the terrarium.

## Bill of Materials

| Item | Quantity | Source 1 | Source 2 | Notes |
| --- | --- | --- | --- | --- |
| Carclo 10140 LED Optics | 5 | [amazon](https://www.amazon.com/dp/B00LWU1G78) ($8.50 for 6) | [LEDsupply](https://www.ledsupply.com/led-optics/10140-carclo-lens-frosted-wide-spot-led-optic) ($1.60 each) | Other carclo 20mm optics will work. Different options include frosted/not-frosted and different illumination patterns / angles. |
| O rings (18mm OD 12mm ID 3mm Width) | 2 | [amazon](https://www.amazon.com/dp/B08HHDG9SX) ($9 for 20) | | |
| Acrylic Sheet - 12" x 24" x 1/32" thick | 1 | [amazon](https://www.amazon.com/dp/B08SW564X3?=) ($10) | | |
| Acrylic Cement | just a bit | [amazon](https://www.amazon.com/dp/B00R5NYM7M) ($18 for 5oz tube)  | | |
| 24v blower fan 30x30x10mm | 2 | [amazon](https://www.amazon.com/dp/B08MKLDGQR) ($10 for 2) | [amazon](https://www.amazon.com/dp/B0CGTRNFZV) ($12 for 6) | |
| Temperature/Humidity Sensor Board | 1 | [amazon](https://www.amazon.com/dp/B0CN32WXJY) ($13 for 3) | | This board needs a cable soldered to it. See the [Electronics Page](/docs/electronics/#sht30-sensor-board-wiring) for details.  |
| 18V 1A+ Power Supply | 1 | [amazon](https://www.amazon.com/dp/B0C7158MH4) ($10) | [digikey](https://www.digikey.com/en/products/detail/globtek-inc/WR9HH1000LCP-F-R6B/10187589) ($5.87) | |
| Ultrasonic Mister Disc | 1 | [amazon](https://www.amazon.com/dp/B0C1C79BH3) ($9 for 3) | | These come with their own circuit boards, which aren't needed because the driver circuit is built into the oasis mainboard. |
| Epoxy Resin | about 80 grams | [amazon](https://www.amazon.com/dp/B07YCVVYFK) ($21 for 960g/34oz) | | |
| Grease | just a bit | [amazon](https://www.amazon.com/dp/B004X70LZA) ($6 for 8oz) | | |
| M3x20mm Socket Cap Screws | 2 | | | |
| M3x8mm Socket Cap Screws | 4 | | | |

### 3D-Printed Parts

| Name          |
| ------------- |
| Top           |
| Bottom        |
| Underplate    |
| Mister Cover  |
| Top Plug      |
| Sensor Basket |

See https://www.printables.com/model/1315117-oasis-smart-terrarium.

### Custom Electronics

This project requires two custom electronics boards: a mainboard and an LED board. See the [Electronics page](/docs/electronics) for more info.

## 3D Printing

This project requires a number of 3d-printed parts. Most of them need to handle high humidity and/or direct contact with water, so it's important to use a material that can handle that. PLA, for example, is a poor choice. I used PETG for this, but ABS and some other plastics should work well.

Model files (STL/STEP) can be downloaded from [printables.com](https://www.printables.com/model/1315117-oasis-smart-terrarium) or [GitHub](https://github.com/justbuchanan/oasis/releases/tag/v1).

### Supports

The only 3d-printed part that needs supports during printing is the sensor basket, which has two small tabs at the top. Tree supports in PrusaSlicer worked well here. All other parts for this project are designed to not need supports.

### PETG Settings

I used a Prusa i3 MK3S+ to print parts in PETG for this project. I initially had some trouble with my first layer of printing, so I've included the settings changes to PrusaSlicer I used below. These print settings are not specific to this project, but may be helpful. My main issue was lack of bed adhesion, so I slowed down the first layer significantly.

- Layers and Perimeters > Quality > Extra perimeters if needed: no -> yes
- Infill density: 15% -> 25%
- Speed > Modifiers > First layer speed: 20mm/s -> 10mm/s
- Speed > Acceleration Control > First layer: 800mm/s^2 -> 600mm/s^2
- Filaments > Temperature > Bed > First Layer: 85C -> 90C

### Waterproofing

There are two printed parts that need to be able to hold water without leaking. While it's _possible_ to get these waterproof straight off of the printer by tweaking your print settings, this is difficult and unlikely to work consistently. I used a low-viscosity epoxy to waterproof the bottom piece as well as the water tank in the top piece.

> [!NOTE]+ Note
> I initially tried to use polyurethane for waterproofing, but found that after two coats, the water tank still leaked. I was eventually able to achieve waterproofing after four coats. Epoxy has consistently worked after just one application.

#### Waterproofing Step-By-Step Guide

Before you begin, you will need the following:

- epoxy
- 3d-printed top piece
- 3d-printed bottom piece
- 3d-printed top plug
- o-ring
- paper towels
- optional: solo cup(s), small funnel, gloves, q-tips, weigh scale

Detailed instructions (with pictures!) follow, but the **tl;dr is: fill the water tank in the top piece with epoxy and slosh it around to fully coat the interior. Drain the excess epoxy into the bottom piece and slosh that around to fully coat its interior. After curing, the pieces will be waterproof.**

Start by mixing up about 80 grams of epoxy (40g part A, 40g part B). This is by no means an exact amount you need to match, but should give you an idea of how much is needed. Follow the instructions that come with your epoxy and be sure to mix well.

Place the o-ring and then the top plug into the top piece.

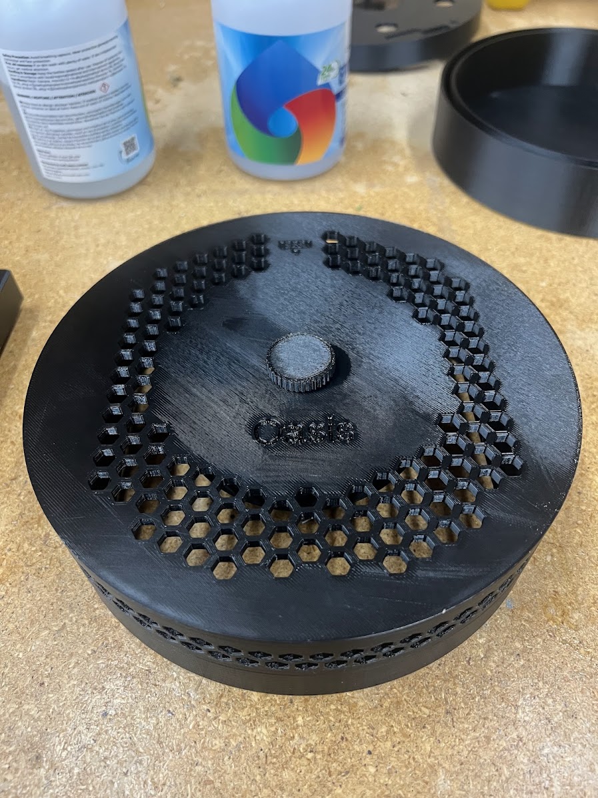
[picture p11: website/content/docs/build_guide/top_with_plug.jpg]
top_with_plug


Place the top piece on a table upside-down, then pour the epoxy into the water tank.

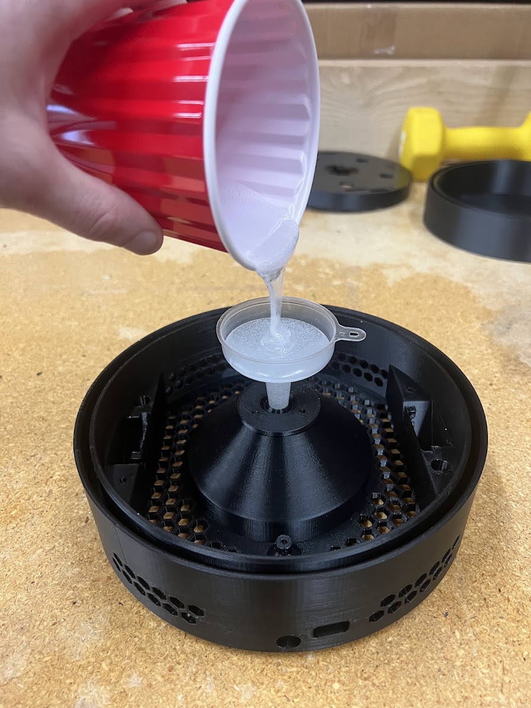
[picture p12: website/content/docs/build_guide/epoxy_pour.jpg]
epoxy_pour


Once the water tank is filled, remove the funnel and cover the hole with a piece of tape or your thumb. Now you'll need to slowly rotate the top piece around to ensure that the epoxy flows around inside the water tank and covers all interior surfaces. Take your time with this and make sure to tilt the piece at every possible angle. It's much better to spend a few extra minutes here making the sure the epoxy covers everything than to later find out that the water tank isn't waterproof. This process should take several minutes.

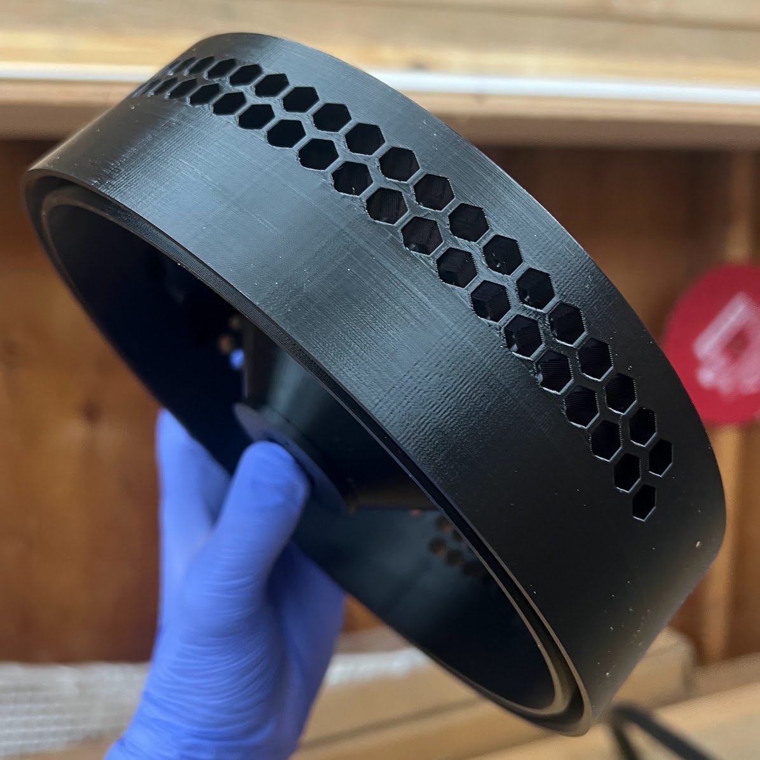
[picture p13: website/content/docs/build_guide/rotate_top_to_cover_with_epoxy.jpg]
rotate_top_to_cover_with_epoxy


Once you've thoroughly coated the interior of the water tank, set the top piece on top of the bottom piece and allow all the excess epoxy to drain out.

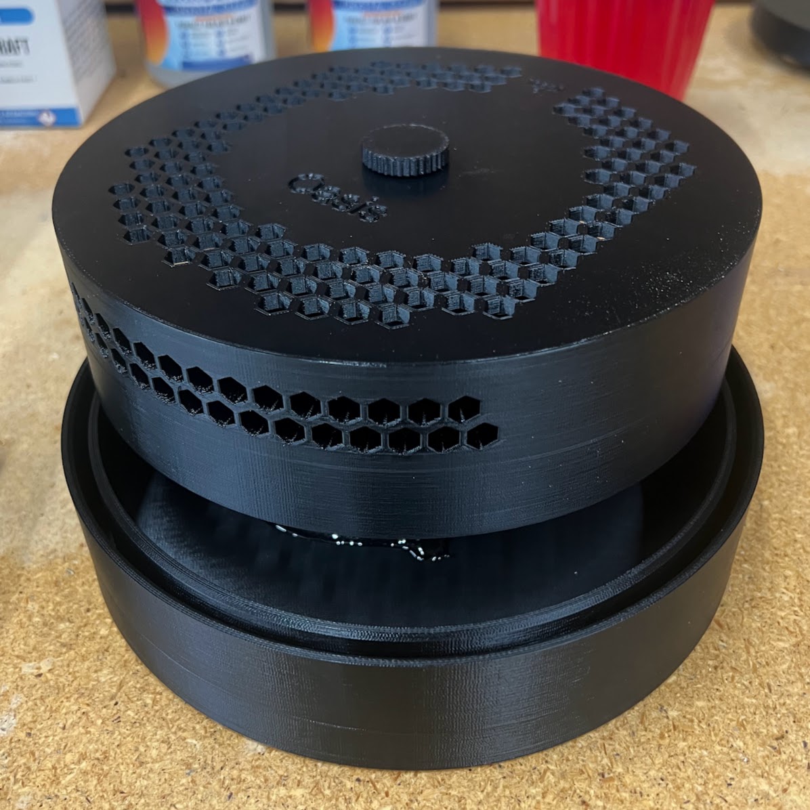
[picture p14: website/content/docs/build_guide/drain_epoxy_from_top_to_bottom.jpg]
drain_epoxy_from_top_to_bottom


Remove the plug and o-ring from the top and wipe them clean of epoxy using a paper towel.

It should take about 5-10 minutes for most of the epoxy to drain from the top piece into the bottom piece. Once that's done, smear a tiny amount of epoxy in the o-ring well of the top piece. Use just enough to coat the surface, but not enough that the o-ring will not fit later. Use a paper towel to wipe up the surface and clean up any excess.

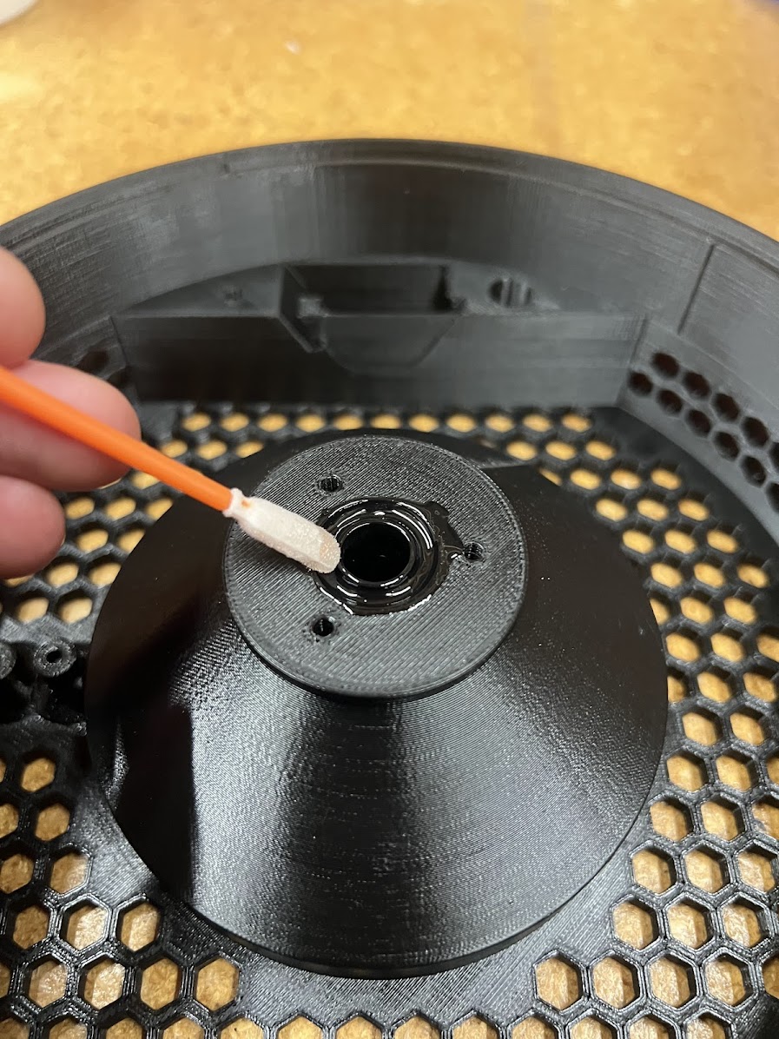
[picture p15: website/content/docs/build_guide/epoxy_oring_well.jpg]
epoxy_oring_well


Set the top piece somewhere (with epoxy entry/exit hole facing down) to continue draining any remaining excess epoxy and to cure. It's worth checking on this an hour or two later and wiping down any epoxy drips that may have formed.

Next step is to coat the interior of the bottom piece with epoxy. Slowly tilt and rotate the piece so that the epoxy covers and coats the entire bottom surface and inside walls. Try your best not to let the epoxy flow into the circular slot that the terrarium walls will later fit into. If this happens, just be sure to clean it out with a paper towel before it cures.

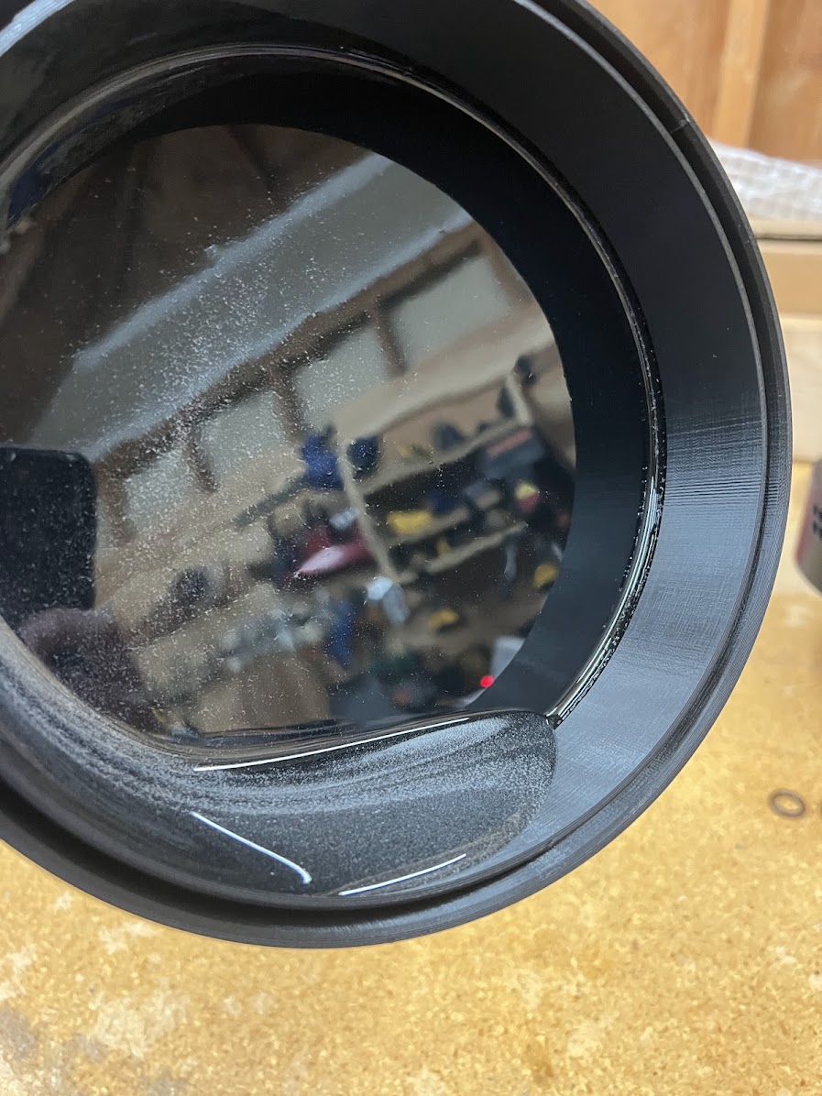
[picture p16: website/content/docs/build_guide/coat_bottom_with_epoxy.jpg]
coat_bottom_with_epoxy


That's about it for waterproofing! Set the bottom piece on a level surface to cure. As mentioned above, you should come back in an hour or two to wipe any excess epoxy drips from the top piece that may have formed. Epoxy typically takes 24 hours to cure, but you should follow the instructions for your specific epoxy.

## Glue Acrylic Sheet to Create The Walls

TODO

## Assembly

Once you've got all the required materials, it's time to put it together!

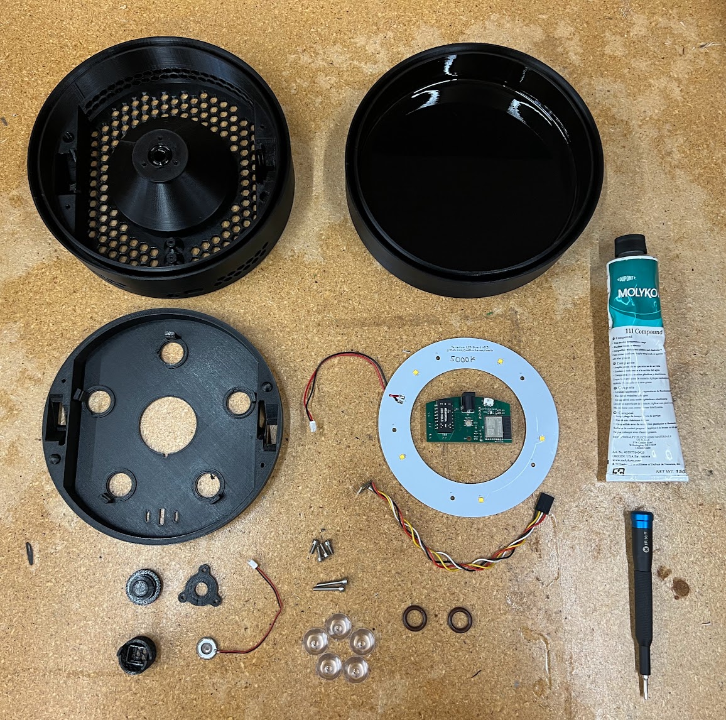
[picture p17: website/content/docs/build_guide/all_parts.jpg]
all_parts


(note: fans are missing in the above photo)

Before starting the build, it may be helpful to take a look at the [Interactive 3D Model](/docs/3dmodel) to visually see how everything comes together.

### LED Optics

Insert the five LED optics into their slots in the 3d-printed "underplate". Each optic has a small rectangular tab that sticks out on one side. Make sure this aligns with the corresponding slot on the 3d print.

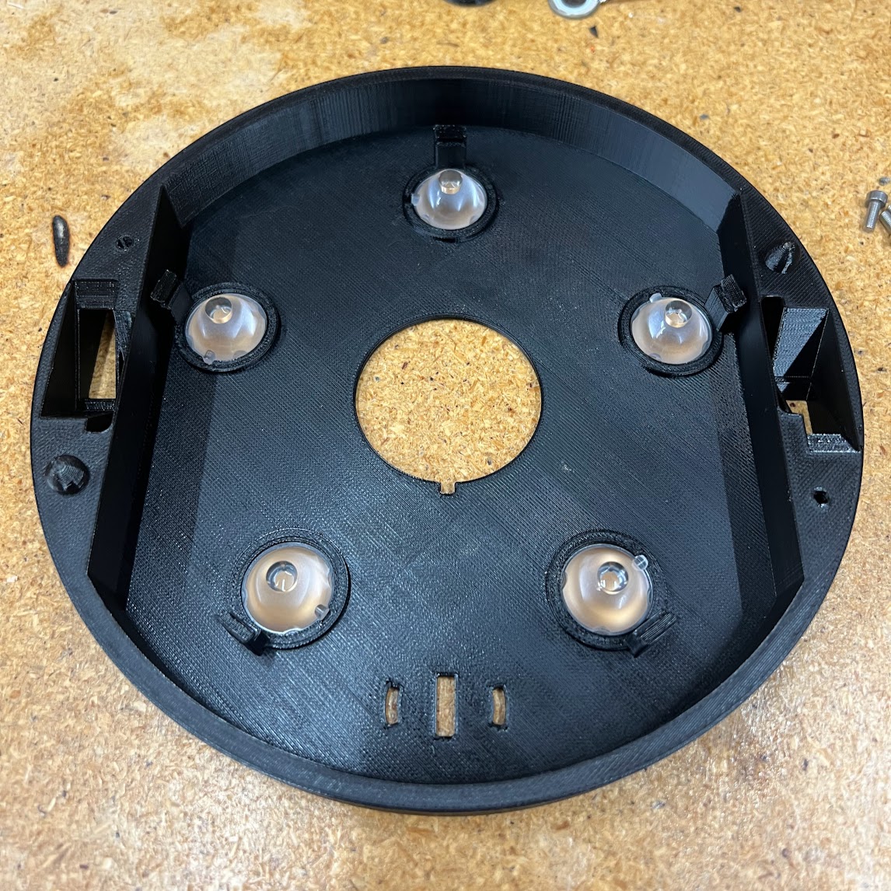
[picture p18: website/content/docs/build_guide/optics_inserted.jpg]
optics_inserted


### Insert the LED board

Align the led board so that the LEDs face down and the power cable points roughly in the direction of the three slots cut out on the underplate. Align the LEDs with their optics and press the board into place. Next to each optic is a 3d-printed clip that will latch onto the led board.

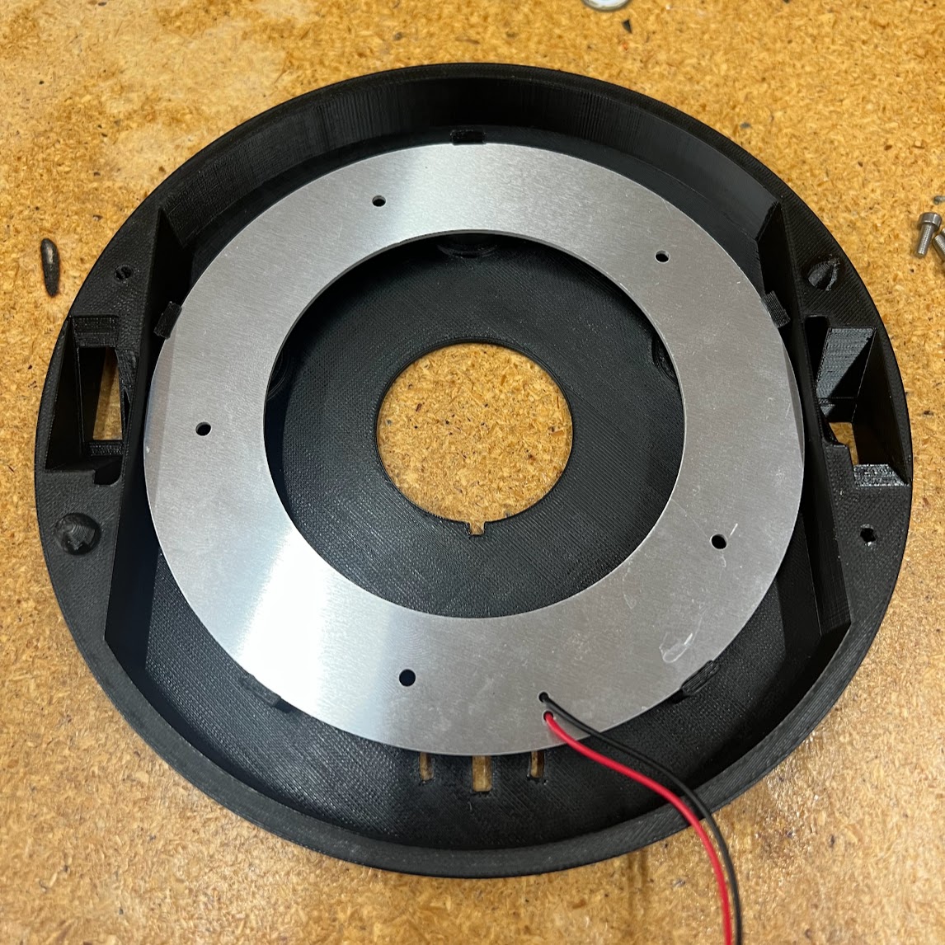
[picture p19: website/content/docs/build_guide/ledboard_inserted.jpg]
ledboard_inserted


### Insert the temperature/humidity sensor

The sht30 temperature/humidity sensor board fits into a rectangular slot in the sensor basket.

> [!WARNING]+ Warning
> The tabs on the top of the sensor basket are very fragile.

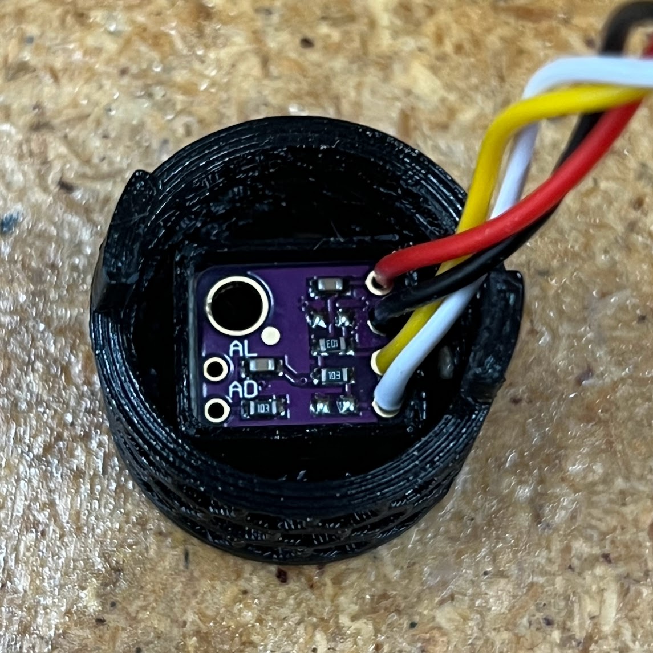
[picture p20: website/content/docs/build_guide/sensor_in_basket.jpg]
sensor_in_basket


### Attach sensor basket to underplate

Start by threading the sensor cable through the slot in the underplate.

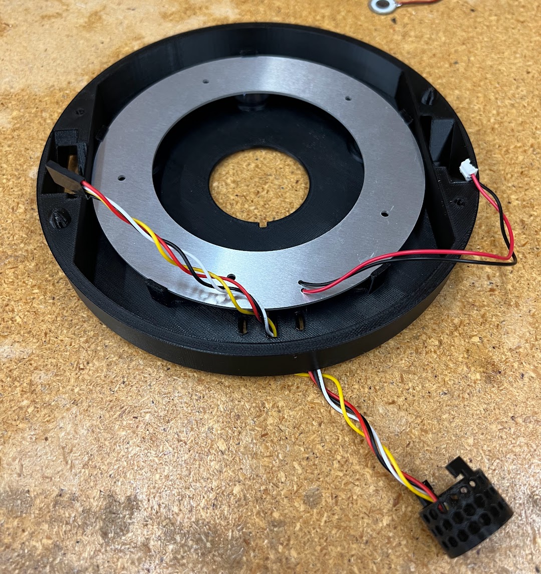
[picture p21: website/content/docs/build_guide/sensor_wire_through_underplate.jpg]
sensor_wire_through_underplate


Next, attach the sensor basket to the underplate by inserting the tabs on the basket through the slots on the underplate. Rotate the sensor basket to engage the tabs.

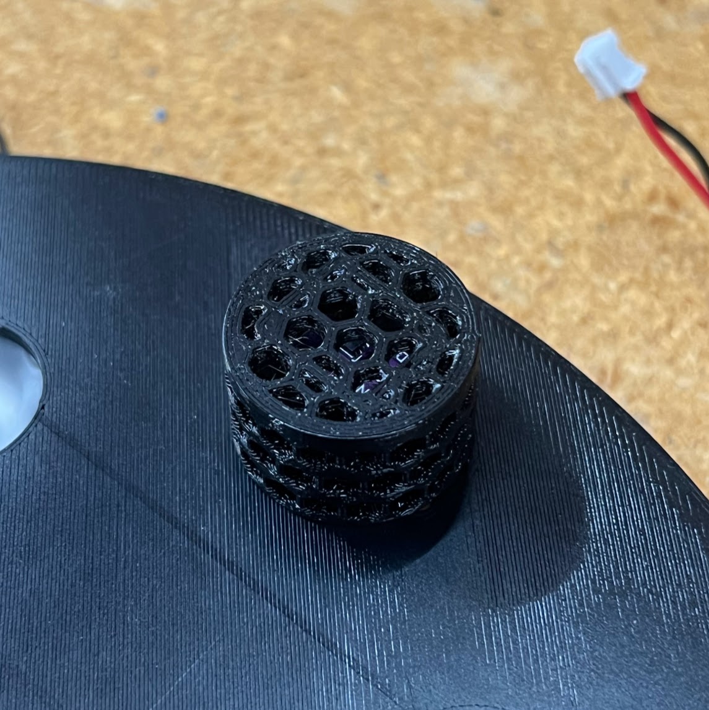
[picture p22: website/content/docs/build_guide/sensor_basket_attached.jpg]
sensor_basket_attached


### Insert the Mainboard

Use an M3x8mm screw to attach the mainboard to the 3d-printed top.

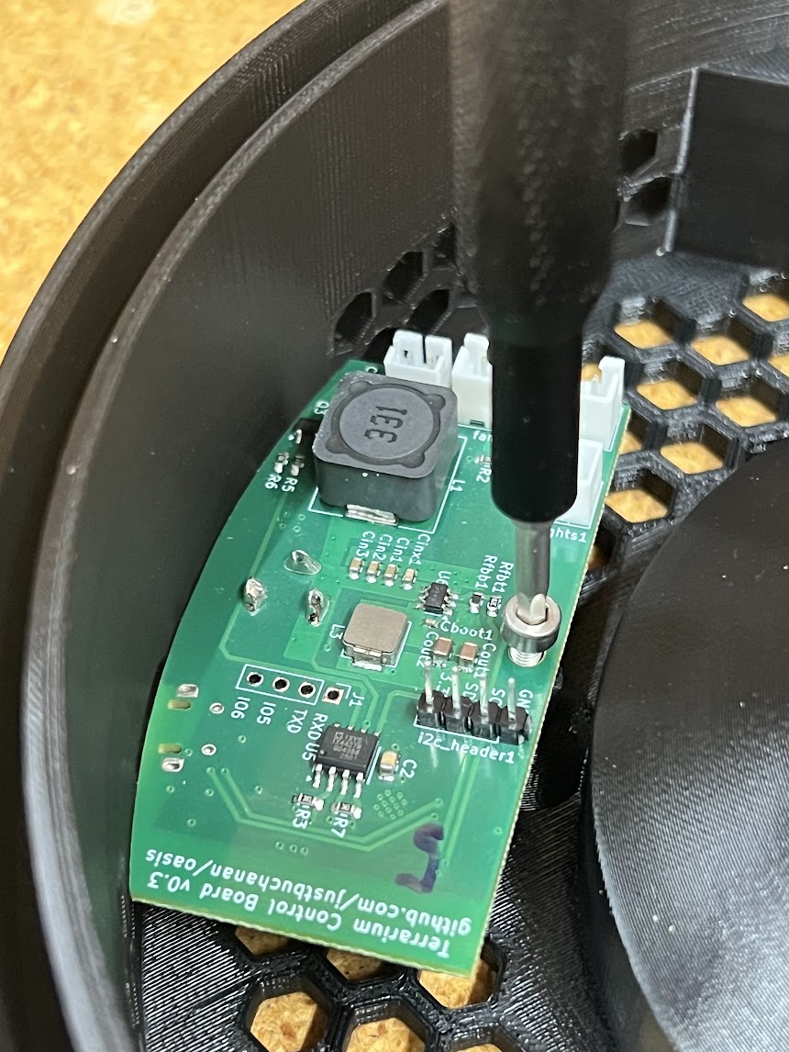
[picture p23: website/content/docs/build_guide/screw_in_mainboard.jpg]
screw_in_mainboard


### Insert the Fans

The top contains a slot on each side that the fans slide into. The cable should point towards the center of the top and pass through the small cutout in the print.

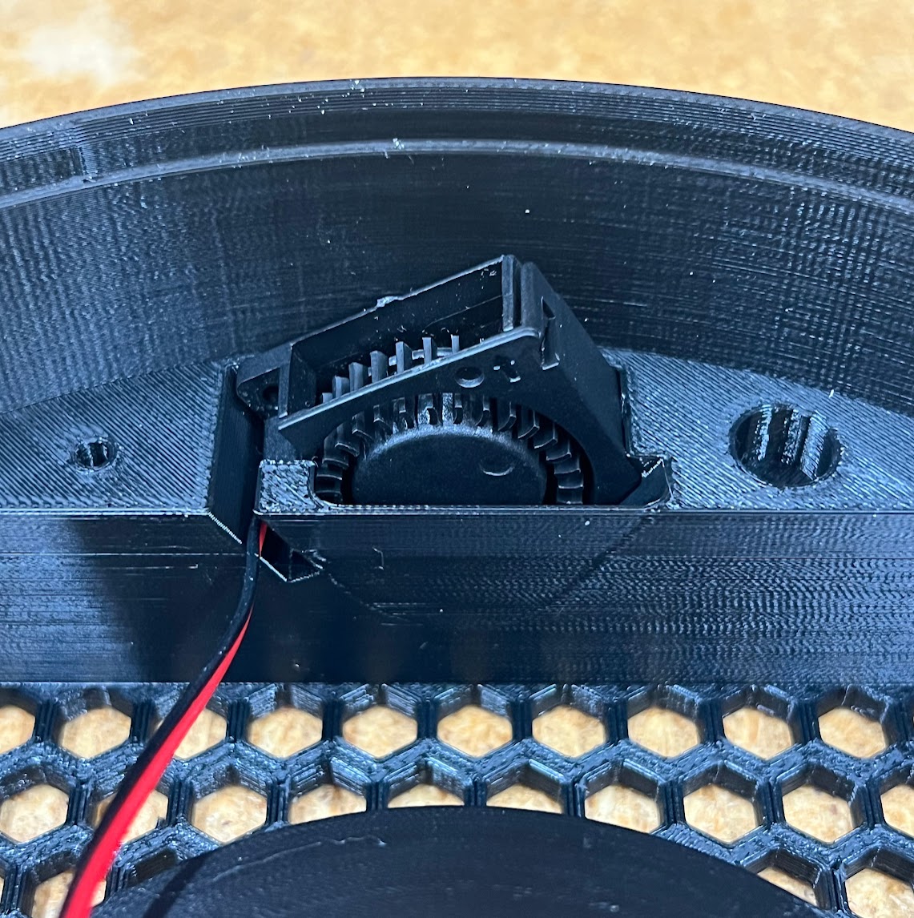
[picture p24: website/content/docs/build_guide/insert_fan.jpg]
insert_fan


### Connect the Fans

Connect the fan power cables to the labeled connectors on the mainboard. Note that fan1 and fan2 are interchangeable - it doesn't matter which fan plugs into which connector.

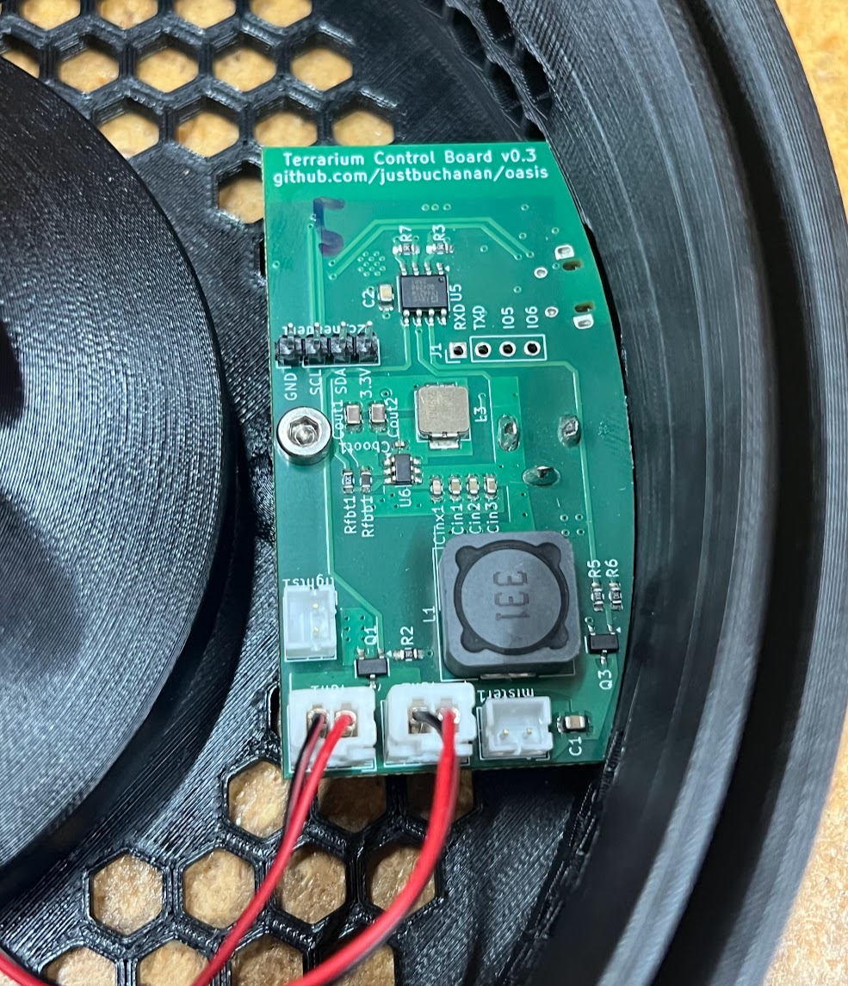
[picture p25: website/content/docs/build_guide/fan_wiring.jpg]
fan_wiring


### Assemble the Mister

> [!WARNING]+ Warning
> The connection point between the wires and the disc is very fragile and prone to breaking apart. Be careful when handling the unit and don't bend the wires excessively.

Start by spreading a small amount of grease on an o-ring, then place it on the o-ring "well" on the water tank.

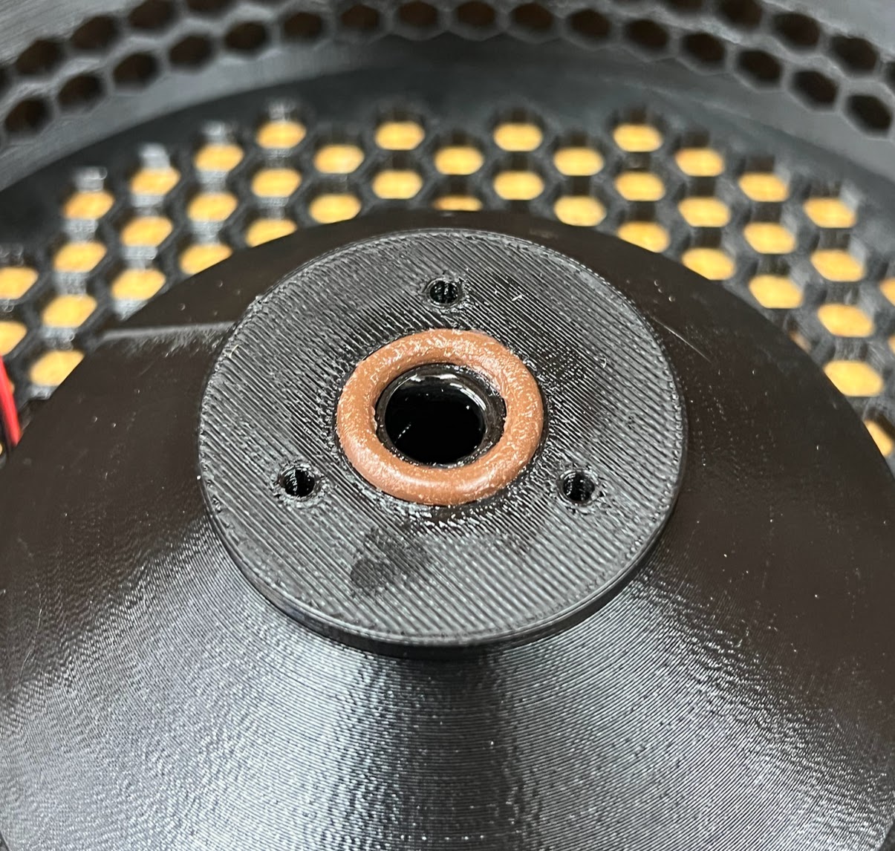
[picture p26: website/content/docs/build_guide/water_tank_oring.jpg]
water_tank_oring


Place the misting disc on top of the o-ring on top of the o-ring, pointing the wire in the direction of the mainboard.

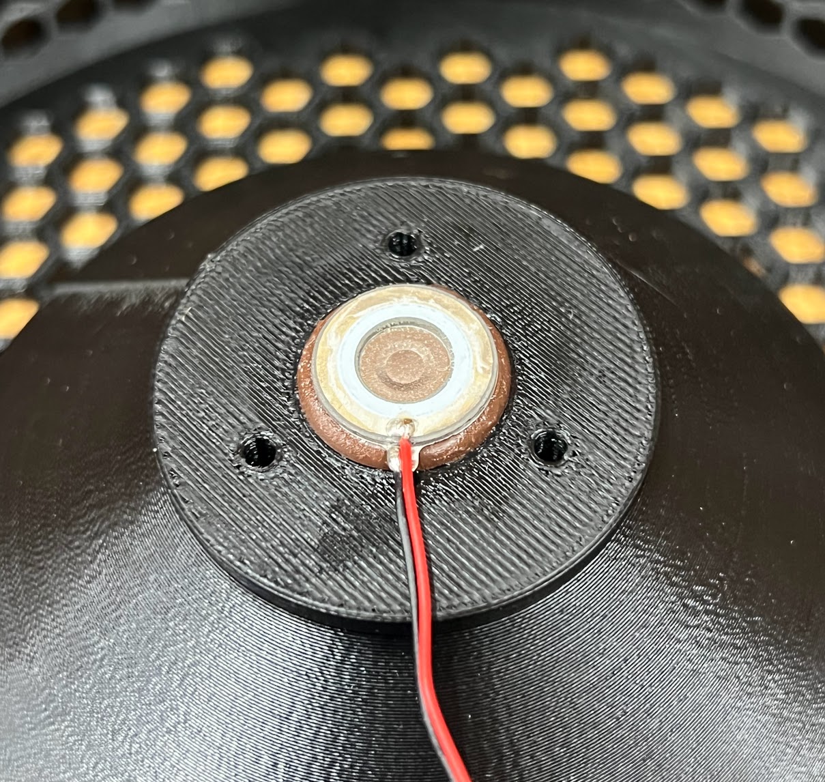
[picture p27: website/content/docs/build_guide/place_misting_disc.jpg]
place_misting_disc


Use three M3x8mm screws to attach the mister cover, taking care to align the slot over the mister cable. Tighten the screws just enough that there's some pressure on the mister, but not more. You may need to come back later to adjust these tighter if water is able to leak around the o-ring or looser if the misting disc is too constrained to produce mist. See the [mister adjustment notes](/docs/usage_guide/#adjusting-the-mister) if needed.

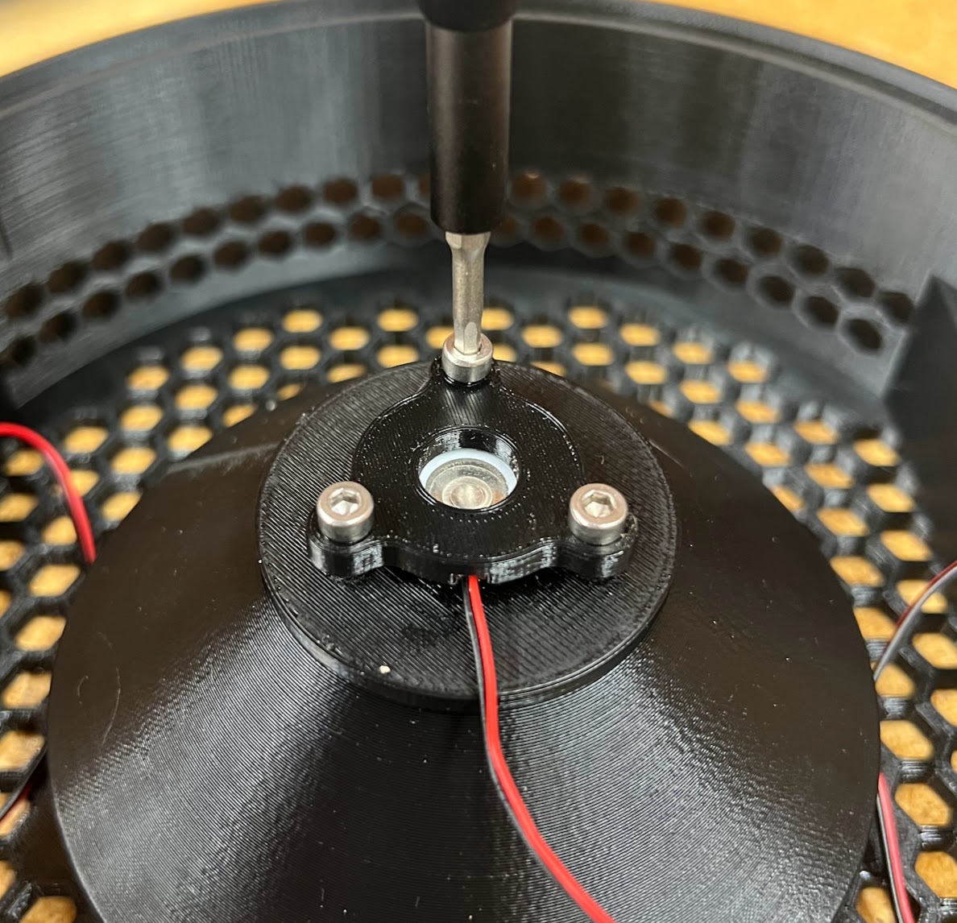
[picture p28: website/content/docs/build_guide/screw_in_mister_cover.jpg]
screw_in_mister_cover


### Plug in Misting Disc

Plug the mister into the labeled connector on the mainboard.

> [!WARNING]+ Warning
> The mister and the lights use the same connector - be careful to plug the mister into the correct one. If you plug it into the wrong connector, use a pair of needle-nose pliers to gently take it out - don't pull it out by the cable.

### Mount the Underplate

Align the top and underplate as shown in the picture below, then connect the LED board power cable and sensor cable to the mainboard.

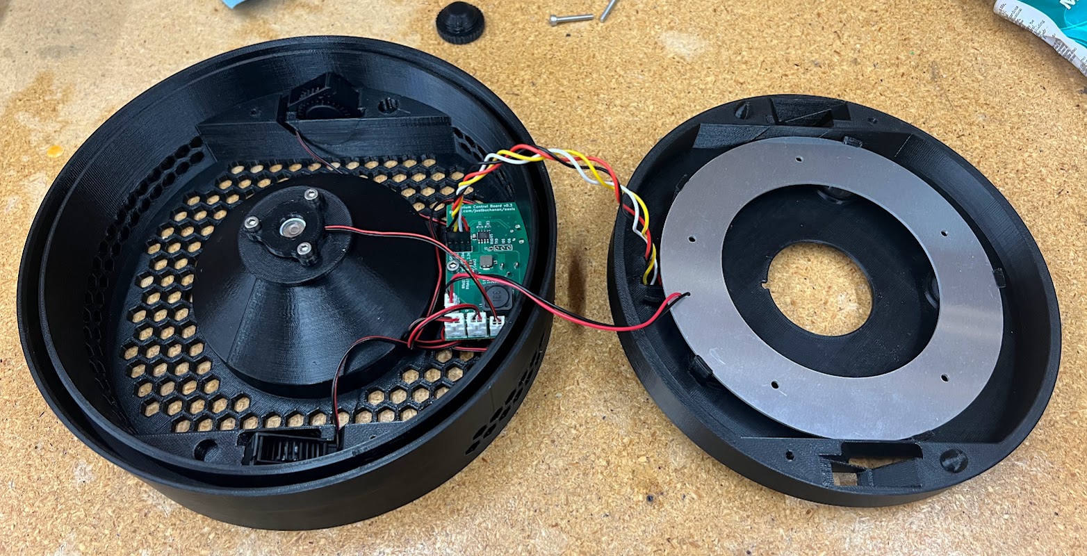
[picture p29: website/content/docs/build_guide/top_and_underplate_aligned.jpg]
top_and_underplate_aligned


Flip the underplate over onto the top piece and align the "registration posts" on the underplate with the corresponding slots in the top piece. Take care not pinch any wires and to route the misting disc cable through the slot in the underplate. Use two M3x20mm screws to hold the parts together.

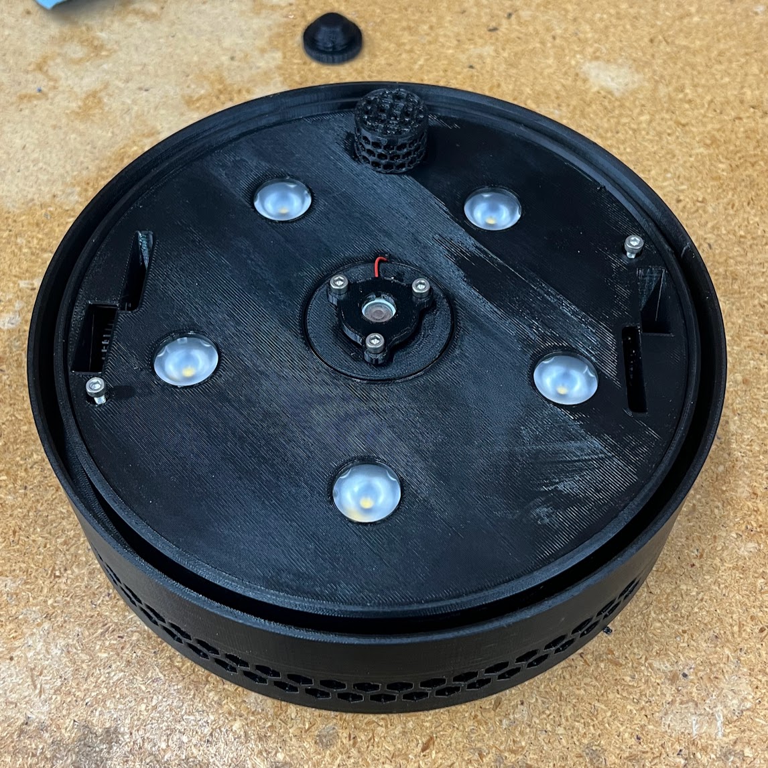
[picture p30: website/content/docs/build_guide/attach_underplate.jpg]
attach_underplate


### Top Plug

Insert an o-ring into the water tank inlet at the top. Grease is optional, but recommended here.

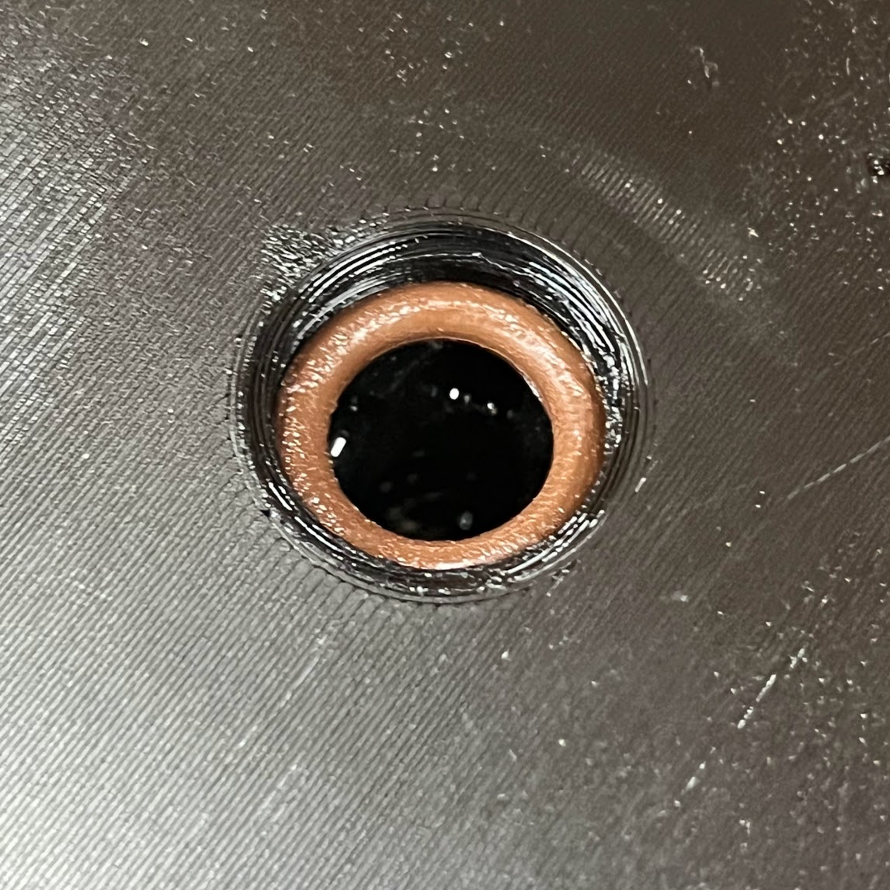
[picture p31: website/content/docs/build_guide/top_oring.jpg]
top_oring


Insert the top plug into the inlet and turn to tighten.

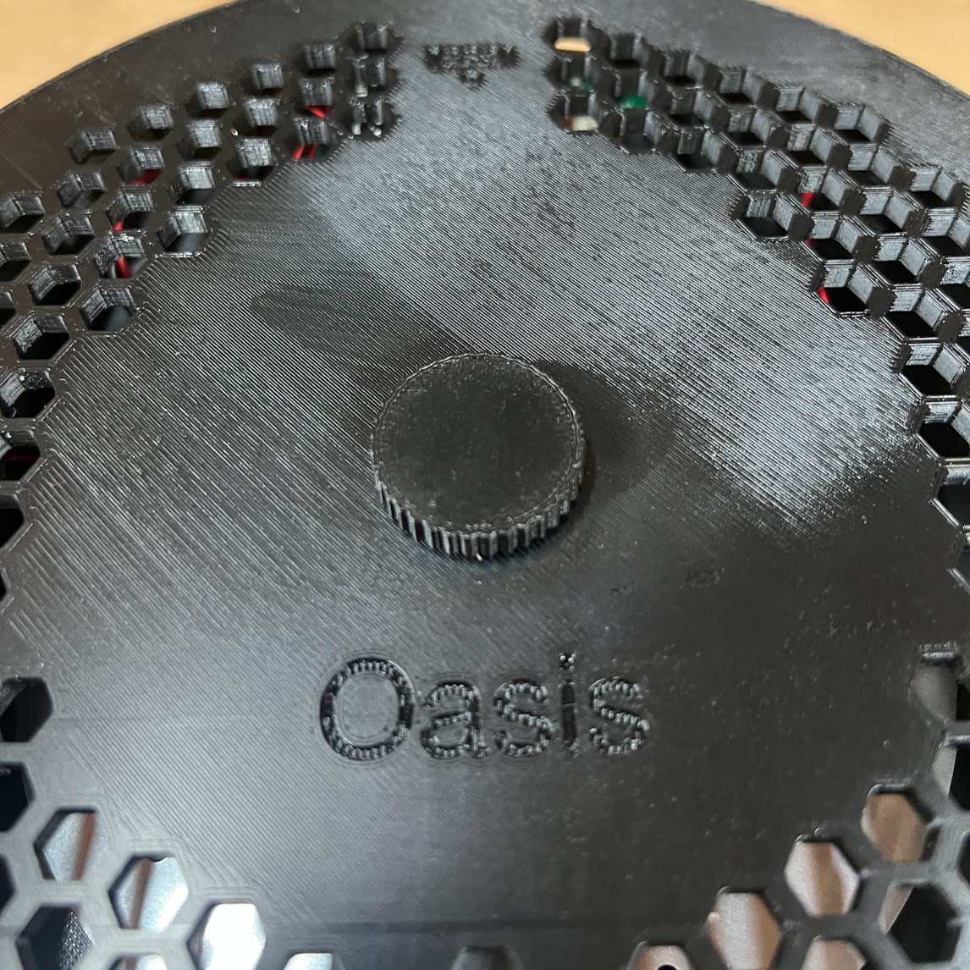
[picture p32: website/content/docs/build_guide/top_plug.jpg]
top_plug


### Final Assembly

Almost done! Insert the acrylic terrarium walls into the the bottom piece, then add the top piece.

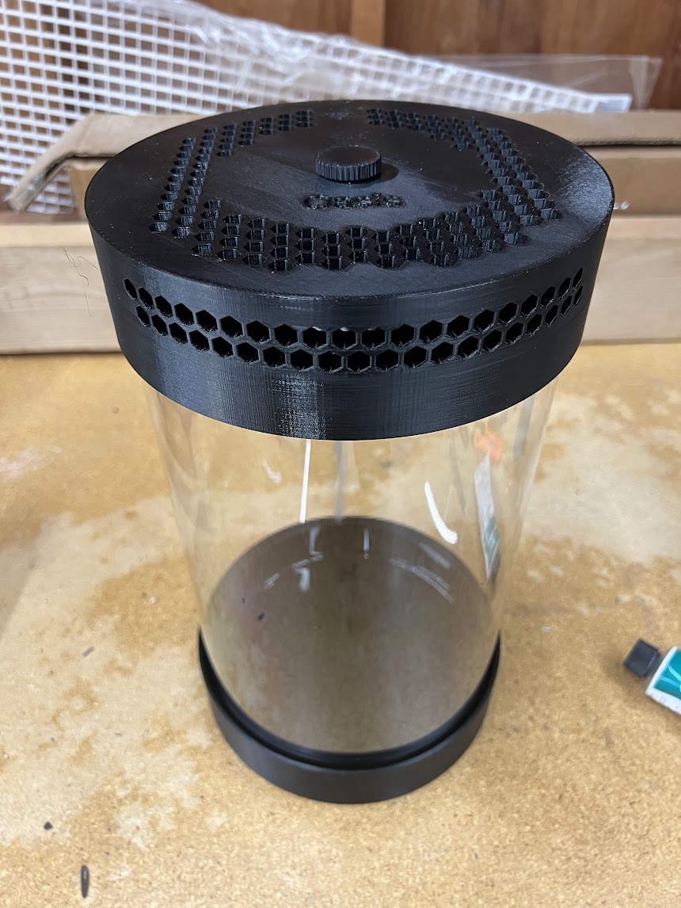
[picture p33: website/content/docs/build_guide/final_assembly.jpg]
final_assembly


## Assembly Complete! What's Next?

Please see the [Usage Guide](/docs/usage_guide) for next steps.

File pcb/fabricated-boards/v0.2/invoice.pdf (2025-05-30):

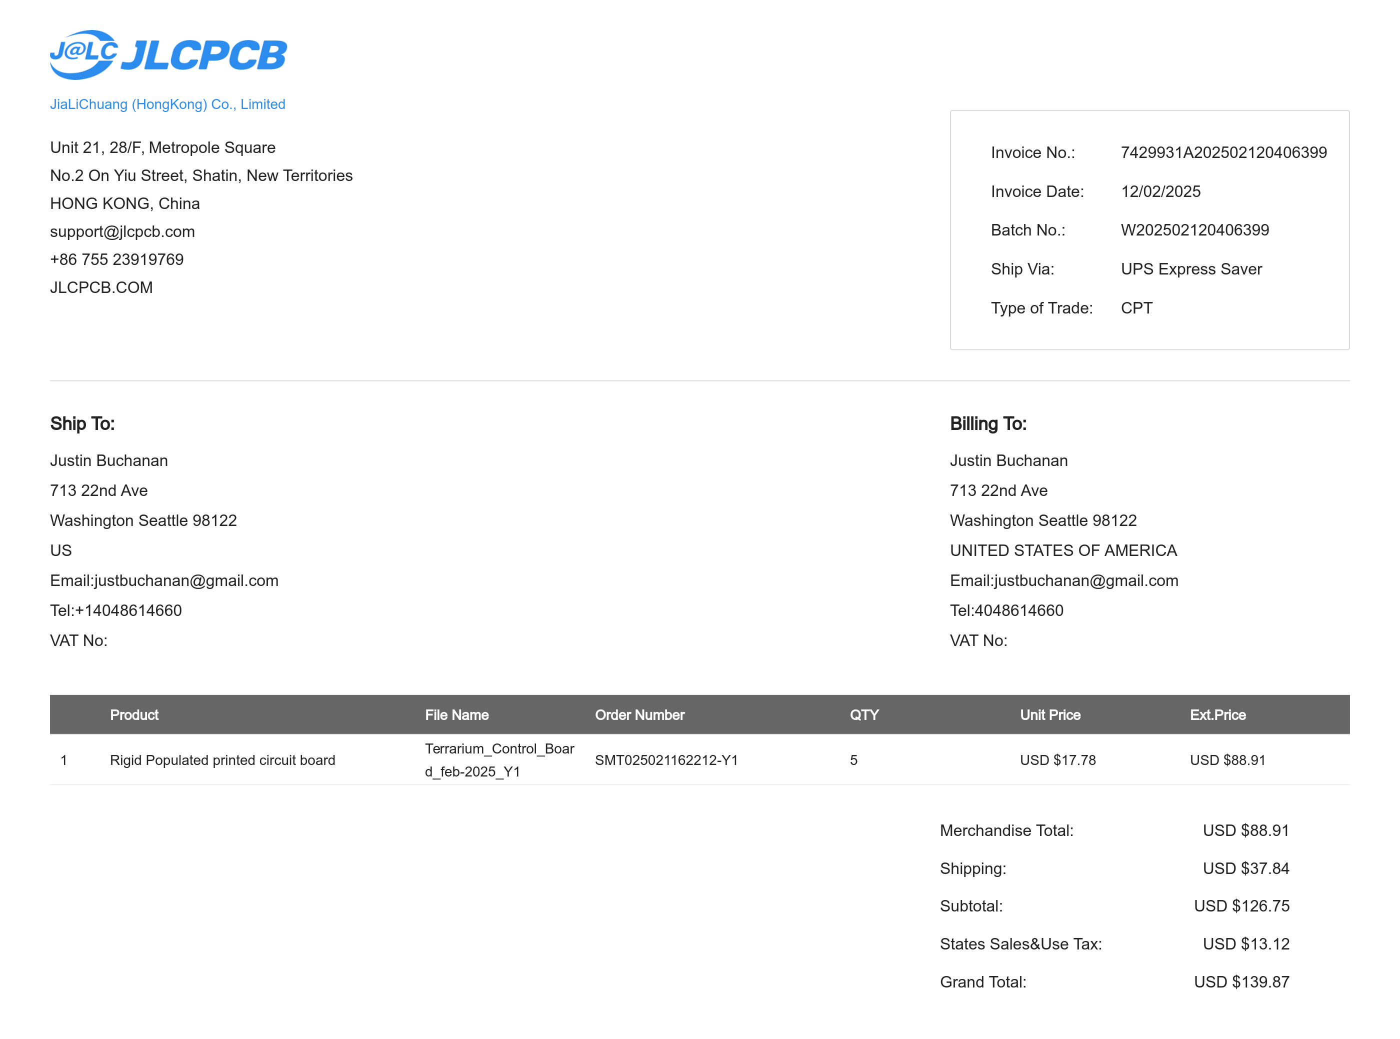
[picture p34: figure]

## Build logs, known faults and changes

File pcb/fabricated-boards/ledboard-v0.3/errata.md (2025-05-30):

## wire holes too small

I made my own footprint for soldering power wires to the board that included two holes for strain releif. The wires don't fit through the holes... need to make them a bit bigger.

## bigger/cleaner traces

Not really an error, but future versions should use larger traces between LEDs and also cleaner shaping/traces.

## Mounting holes no longer needed

Mounting method changed, so we don't need the holes.

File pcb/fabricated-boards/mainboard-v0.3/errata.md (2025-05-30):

## make usb traces same length

Probably doesn't matter at the speeds we're doing, but the traces between the esp32 and the usb connector should be the same length. Look into using the "differential pair" routing tool in kicad.

## Arc radius changed

Since the design of this board, the overall radius of the terrarium shrunk a couple millimeters. The arc radius of the mainboard should be changed to account for this, ideally without changing the distance from the hole and buttons to the outer edge of the board. Note that the change in radius is small enough that the fabricated board fits in the smaller terrarium design without issue.

## better mounting hole

consider using a plated hole with vias for better strength

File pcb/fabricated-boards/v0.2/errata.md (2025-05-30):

# Rfbb1 wrong size

shortly after submitting the design through the jlcpcb website, they reached out to let me know that there was an issue with Rfbb1. I had accidentally selected an 0402 resistor, but the footprint on the board design was for an 0603. They gave me the option to select the correct part.

old PN: C844504
new PN: C844759

note: the bom and such in this directory reflect the old part number.

# mister1 connector wrong rotation / wrong pin numbers

pin numbers are right. pin 1 is vcc (sort of), pin 2 is gnd.

the issue is that the part on the jlcpcb order is rotated 180 from what I have in my pcb layout in kicad. this might be a mistake in jlcpcb 3d viewer or a translation issue between kicad and jlc. could possibly be fixed with fabrication toolkit by adding a "FT Rotation Offset: 180" to the part attributes in kicad.

I contacted jlcpcb support and had them fix it before assembly.

TODO: adjust the kicad design so that this doesn't happen next time.

# Gate and source are swapped on the footprint for the fan and mister mosfets

see datasheet here: https://wmsc.lcsc.com/wmsc/upload/file/pdf/v2/lcsc/2307110943_VBsemi-Elec-SI2328DS-T1-GE3_C7420571.pdf

I was able to fix this by desoldering both mosfets, flipping them upside down and rotating a bit, and commiting crimes against soldering. The board is fully working now!

# power input connection/holes are too big

Not causing any issues at all, but make them a bit smaller next time.

# buttons aren't actually necessary

I'm not sure if the en and boot boot buttons are actually useful at all. Since we're using the builtin usb support of the c3, all programming can be done over usb without any button presses. It's possible we can re-use the buttons for something else and it's possible the en (reset?) button is still useful, but I haven't used either of them once yet. Consider removing the buttons on the next iteration or re-purposing them.

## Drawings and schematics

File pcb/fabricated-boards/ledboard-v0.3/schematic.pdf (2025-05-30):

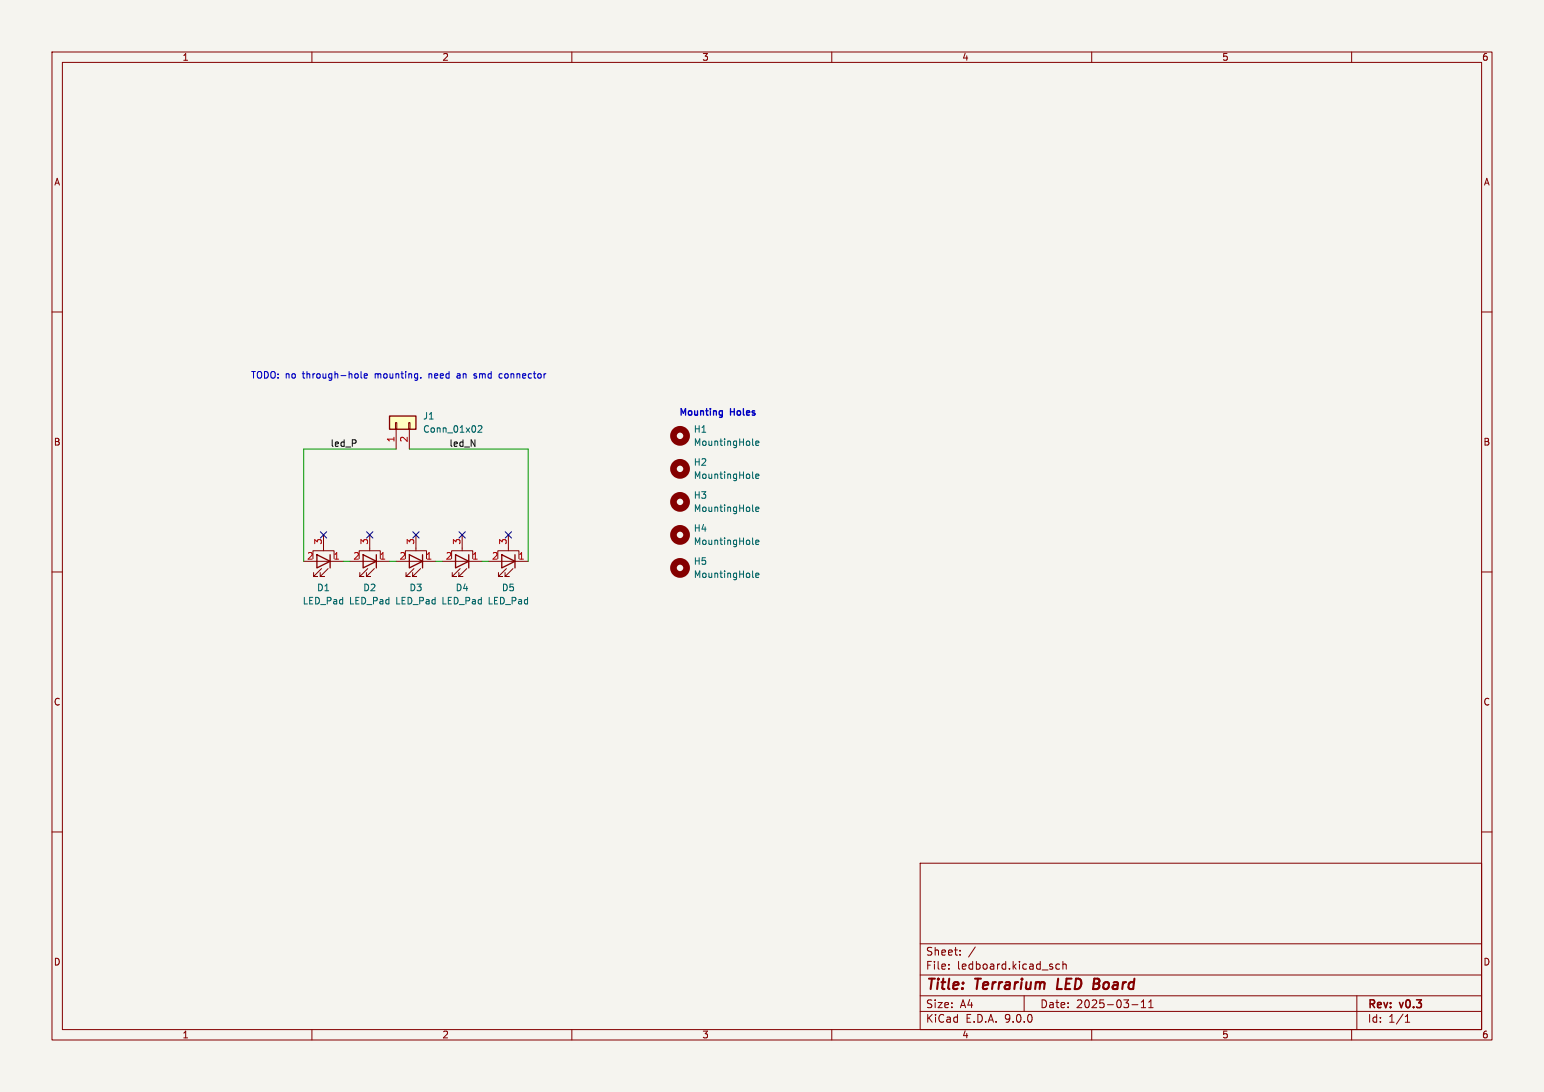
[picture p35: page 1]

File: ledboard.kicad_sch Sheet: /
Id: 1/1 Title: Terrarium LED Board

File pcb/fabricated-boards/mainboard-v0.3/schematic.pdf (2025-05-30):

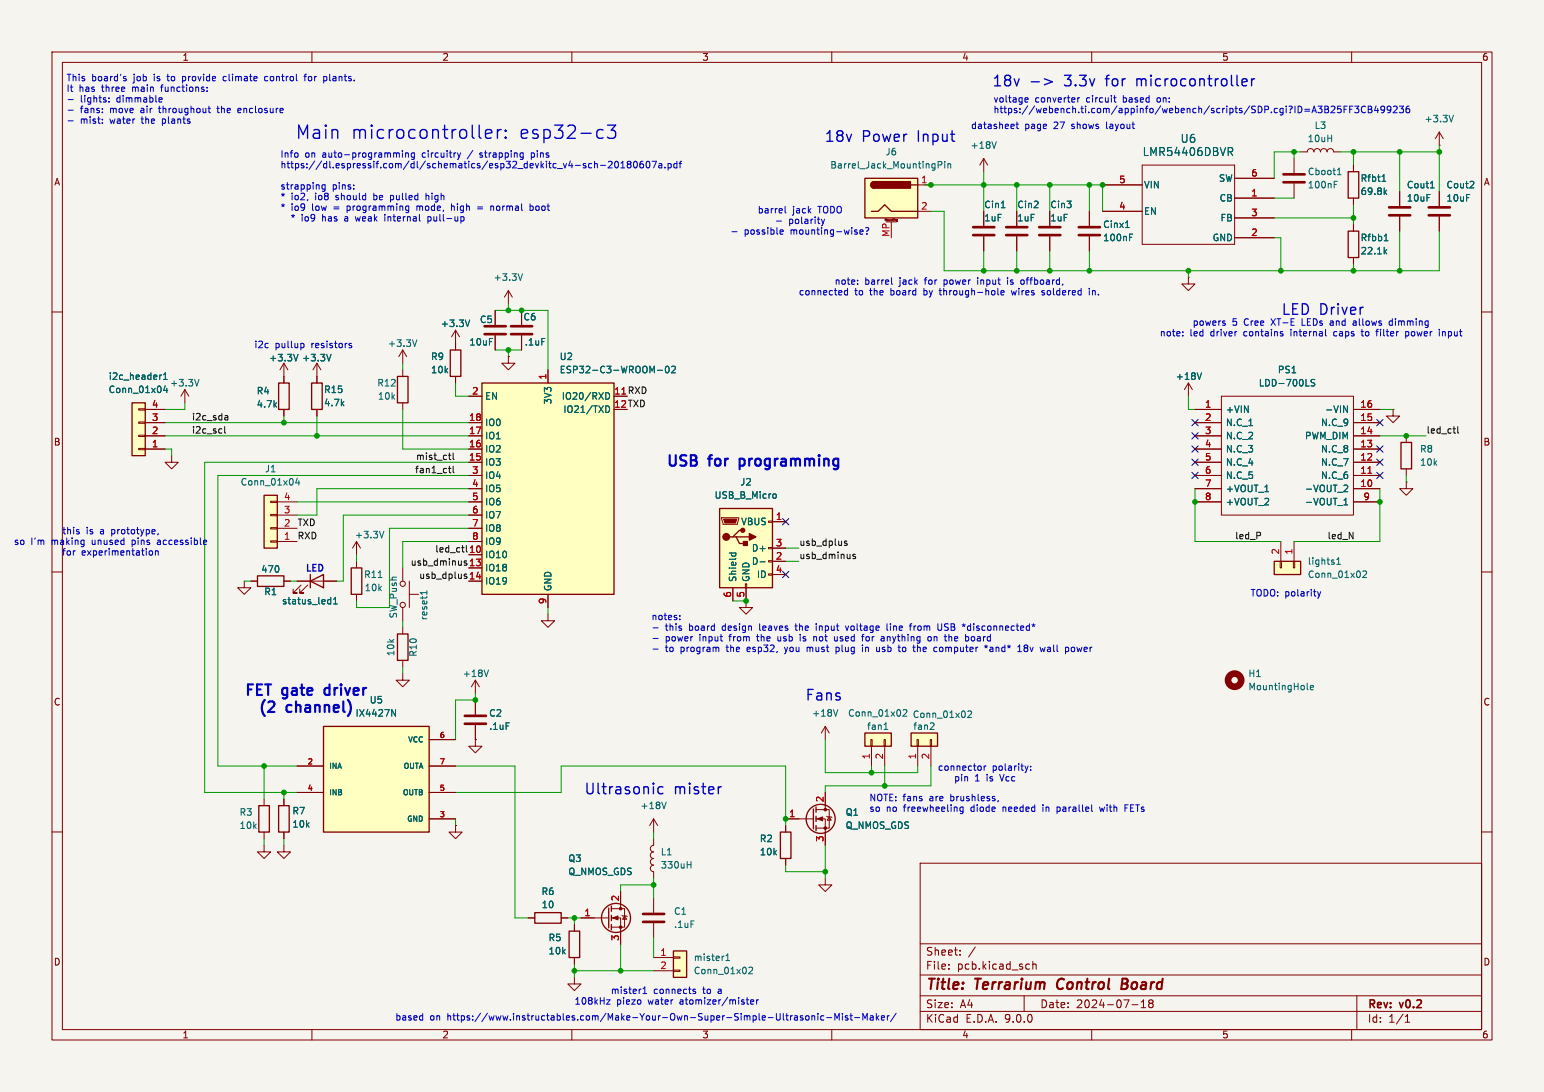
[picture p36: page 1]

It has three main functions: - lights: dimmable

- mist: water the plants

https://dl.espressif.com/dl/schematics/esp32_devkitc_v4-sch-20180607a.pdf

powers 5 Cree XT-E LEDs and allows dimming

this is a prototype, so I'm making unused pins accessible

notes: - this board design leaves the input voltage line from USB *disconnected*

File: pcb.kicad_sch Sheet: /
Id: 1/1 Title: Terrarium Control Board

108kHz piezo water atomizer/mister based on https://www.instructables.com/Make-Your-Own-Super-Simple-Ultrasonic-Mist-Maker/

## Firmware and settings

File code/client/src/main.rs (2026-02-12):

// This file defines the command-line client program for the Oasis terrarium.
//
// This program can be used to query the state of the terrarium, configure it's
// schedule, and control its lights, mist, and fans.

use anyhow::anyhow;
use clap::{Parser, Subcommand};
use itertools::Itertools;
use mdns_sd::{ServiceDaemon, ServiceEvent};
use regex::Regex;
use reqwest::StatusCode;
use std::collections::{HashMap, HashSet};
use std::env;
use std::fmt;
use std::fs::File;
use std::io::BufReader;
use std::time::Duration;
use terralib::config::TerrariumConfigUpdate;
use terralib::terrarium::print_terrarium_state;
use terralib::types::{
    Actuator, ActuatorOverride, ActuatorOverrideSet, ActuatorValue, TerrariumState,
};

#[derive(Parser, Debug)]
#[command(about = "Oasis terrarium command-line client")]
struct Args {
    #[arg(long, help = "Hostname or IP address of terrarium")]
    addr: Option<String>,

    #[command(subcommand)]
    command: Commands,
}

#[derive(Subcommand, Debug)]
enum Commands {
    /// Control the lights, fans, and mister.
    Ctl {
        #[arg(help = "A list of actuator commands of the form <actuator>@<value>:<duration>")]
        overrides: Vec<String>,
    },
    /// Get the temperature and humidity of the terrarium, as well as the current state of the lights, fans, and mister.
    State {
        #[arg(long, help = "If true, output is printed in json format")]
        json: bool,
    },
    /// Get or set the terrarium configuration. This includes wifi details and schedule.
    Config {
        #[arg(long)]
        config_json: Option<String>,
        #[arg(long)]
        config_file: Option<String>,
    },
    /// Scan the local network for online terrariums.
    Scan {
        #[arg(help = "How long to scan mdns for (in seconds)", value_parser = parse_duration, default_value = "10")]
        timeout: Duration,
    },
}

fn parse_duration(arg: &str) -> Result<Duration, std::num::ParseIntError> {
    let seconds = arg.parse()?;
    Ok(Duration::from_secs(seconds))
}

#[tokio::main]
async fn main() -> anyhow::Result<()> {
    stderrlog::new()
        .module(module_path!())
        .verbosity(log::Level::Info)
        .init()
        .unwrap();

    let args = Args::parse();

    // The terrarium address can be passed by flag or environment variable. Flag
    // takes precedence. Only required for commands that connect to a specific terrarium.
    let get_addr = || {
        args.addr
            .clone()
            .or(env::var("OASIS_ADDR").ok())
            .expect("No address specified. Either pass --addr or set OASIS_ADDR env var.")
    };

    match &args.command {
        Commands::Ctl { overrides } => {
            let addr = get_addr();
            log::info!("Connecting to terrarium at '{addr}'...");
            let client = reqwest::Client::new();

            let cmds: Result<Vec<ControlCommand>, CommandParseError> =
                overrides.iter().map(|x| parse_cmd(x)).collect();
            match cmds {
                Ok(_) => {}
                Err(ref err) => {
                    panic!("Error parsing command(s): {err}");
                }
            }

            let update_data = create_update_data(&cmds.unwrap());
            let control_uri = format!("http://{addr}/control");
            let resp = client.post(control_uri).json(&update_data).send().await?;
            if resp.status() != StatusCode::OK {
                return Err(anyhow!("Control failed: {}", resp.text().await?));
            }
        }
        Commands::State { json } => {
            let addr = get_addr();
            log::info!("Connecting to terrarium at '{addr}'...");
            let client = reqwest::Client::new();

            let state_uri = format!("http://{addr}/state");
            let resp = client.get(state_uri).send().await?;
            if resp.status() != StatusCode::OK {
                return Err(anyhow!(
                    "Got bad response: {}",
                    resp.text().await.expect("resp text")
                ));
            }

            let text = resp.text().await.unwrap();
            if *json {
                println!("{text}");
            } else {
                let state: TerrariumState = serde_json::from_str(&text).unwrap();
                println!("Terrarium State:");
                println!("================");
                print_terrarium_state(&state);
            }
        }
        Commands::Config {
            config_json,
            config_file,
        } => {
            let addr = get_addr();
            log::info!("Connecting to terrarium at '{addr}'...");
            let client = reqwest::Client::new();

            let config_uri = format!("http://{addr}/config");
            if let Some(cfg) = config_json {
                let config_data: TerrariumConfigUpdate = serde_json::from_str(cfg)?;
                let resp = client.post(config_uri).json(&config_data).send().await?;
                if resp.status() != StatusCode::OK {
                    return Err(anyhow!(
                        "Got bad response: {}",
                        resp.text().await.expect("resp text")
                    ));
                }
            } else if let Some(cfg_file) = config_file {
                let file = File::open(cfg_file).expect("file read");
                let reader = BufReader::new(file);
                let config_data: TerrariumConfigUpdate = serde_json::from_reader(reader)?;
                let resp = client.post(config_uri).json(&config_data).send().await?;
                if resp.status() != StatusCode::OK {
                    return Err(anyhow!(
                        "Got bad response: {}",
                        resp.text().await.expect("resp text")
                    ));
                }
            } else {
                let resp = client.get(config_uri).send().await?;
                if resp.status() != StatusCode::OK {
                    return Err(anyhow!(
                        "Got bad response: {}",
                        resp.text().await.expect("resp text")
                    ));
                }

                let text = resp.text().await.unwrap();
                println!("{text}");
            }
        }
        Commands::Scan { timeout } => {
            // Create a daemon
            let mdns = ServiceDaemon::new().expect("Failed to create daemon");

            // Browse for a service type.
            let service_type = "_oasis_terrarium._tcp.local.";
            let receiver = mdns.browse(service_type).expect("Failed to browse");

            // Keep track of entries we've seen before to avoid printing duplicates.
            let mut found = HashSet::new();

            // Receive the browse events in sync or async. Here is
            // an example of using a thread. Users can call `receiver.recv_async().await`
            // if running in async environment.
            log::info!(
                "Scanning local network (mdns) for {}s...",
                timeout.as_secs()
            );
            std::thread::spawn(move || {
                while let Ok(event) = receiver.recv() {
                    match event {
                        ServiceEvent::ServiceResolved(full_info) => {
                            let ip = full_info
                                .get_addresses_v4()
                                .iter()
                                .exactly_one()
                                .expect("one and only one ip address")
                                .to_string();

                            let info = MdnsInfo {
                                fullname: full_info.get_fullname().into(),
                                hostname: full_info
                                    .get_hostname()
                                    .strip_suffix(".")
                                    .expect("")
                                    .into(),
                                ip,
                            };
                            let is_new = found.insert(info.clone());
                            if is_new {
                                println!(
                                    "Detected terrarium with hostname '{}', ip address: '{}'",
                                    info.hostname, info.ip
                                );
                            }
                        }
                        _other_event => {
                            // println!("Received other event: {:?}", &other_event);
                        }
                    }
                }
            });

            // Gracefully shutdown the daemon after waiting a bit.
            std::thread::sleep(*timeout);
            mdns.shutdown().unwrap();
        }
    }

    Ok(())
}

#[derive(PartialEq, Eq, Hash, Clone)]
struct MdnsInfo {
    ip: String,
    fullname: String,
    hostname: String,
}

fn create_update_data(cmds: &[ControlCommand]) -> ActuatorOverrideSet {
    let updates = cmds
        .iter()
        .map(|cmd| {
            let val = if cmd.actuator == Actuator::Mist || cmd.actuator == Actuator::Fans {
                ActuatorValue::Bool(cmd.value > 0.0)
            } else {
                ActuatorValue::Float(cmd.value)
            };
            ActuatorOverride {
                actuator: cmd.actuator,
                value: val,
                duration_secs: cmd.duration as u32,
            }
        })
        .collect();

    ActuatorOverrideSet { updates }
}

#[derive(PartialEq, Debug)]
struct ControlCommand {
    actuator: Actuator,
    value: f32,    // TODO: or bool
    duration: f32, // in seconds
}

// TODO: consider using anyhow error instead since all we're doing is recording an error message
#[derive(PartialEq, Debug)]
struct CommandParseError {
    msg: String,
}

impl CommandParseError {
    pub fn new(msg: &str) -> Self {
        Self { msg: msg.into() }
    }
}

impl fmt::Display for CommandParseError {
    fn fmt(&self, f: &mut fmt::Formatter<'_>) -> fmt::Result {
        write!(f, "{}", self.msg)
    }
}

const DEFAULT_DURATION: f32 = 60.0;

// TODO: mist and fan should be 0 or 1, lights should be in [0, 1]
fn parse_cmd(cmd: &str) -> Result<ControlCommand, CommandParseError> {
    if cmd.is_empty() {
        return Err(CommandParseError::new("Empty command"));
    }

    let abbrev_map = HashMap::from([
        ("m", Actuator::Mist),
        ("l", Actuator::Lights),
        ("f", Actuator::Fans),
    ]);

    let re = Regex::new(
        r"^(?<abbrev>[a-zA-Z])(@(?<value>[0-9]*(\.[0-9]+)?))?(:(?<duration>[0-9]*(\.[0-9]+)?))?$",
    )
    .unwrap();
    let caps = match re.captures(cmd) {
        Some(c) => c,
        None => {
            return Err(CommandParseError::new(&format!("Invalid command: '{cmd}'")));
        }
    };

    let abbrev = caps.name("abbrev").unwrap().as_str();
    let actuator = match abbrev_map.get(abbrev.to_lowercase().as_str()) {
        Some(actuator) => *actuator,
        None => {
            return Err(CommandParseError::new(&format!(
                "Invalid abbreviation: '{abbrev}'"
            )));
        }
    };

    let value = match caps.name("value") {
        Some(mstr) => mstr.as_str().parse::<f32>().unwrap_or(0.0),
        None => {
            // If no explicit value is given, use 1 if abbrev is uppercase, else
            // 0.
            if abbrev.chars().all(|x| x.is_uppercase()) {
                1.0
            } else {
                0.0
            }
        }
    };

    let duration = match caps.name("duration") {
        Some(mstr) => mstr.as_str().parse::<f32>().unwrap_or(0.0),
        None => DEFAULT_DURATION,
    };

    Ok(ControlCommand {
        actuator,
        value,
        duration,
    })
}

#[cfg(test)]
mod parse_cmd {
    use super::*;

    #[test]
    fn full_cmd() {
        assert_eq!(
            parse_cmd("m@1:2"),
            Ok(ControlCommand {
                actuator: Actuator::Mist,
                value: 1.0,
                duration: 2.0,
            })
        );
    }

    #[test]
    fn only_duration() {
        assert_eq!(
            parse_cmd("m:2"),
            Ok(ControlCommand {
                actuator: Actuator::Mist,
                value: 0.0,
                duration: 2.0,
            })
        );
    }

    #[test]
    fn only_value() {
        assert_eq!(
            parse_cmd("m@1"),
            Ok(ControlCommand {
                actuator: Actuator::Mist,
                value: 1.0,
                duration: DEFAULT_DURATION,
            })
        );
    }

    #[test]
    fn uppercase_abbrev() {
        assert_eq!(
            parse_cmd("M:2"),
            Ok(ControlCommand {
                actuator: Actuator::Mist,
                value: 1.0,
                duration: 2.0,
            })
        );
    }

    #[test]
    fn decimals() {
        assert_eq!(
            parse_cmd("l@0.5:0.5"),
            Ok(ControlCommand {
                actuator: Actuator::Lights,
                value: 0.5,
                duration: 0.5,
            })
        );
    }

    #[test]
    fn invalid_abbrev() {
        assert_eq!(
            parse_cmd("x:2"),
            Err(CommandParseError::new("Invalid abbreviation: 'x'")),
        );
    }

    #[test]
    fn invalid_command() {
        assert_eq!(
            parse_cmd("abc"),
            Err(CommandParseError::new("Invalid command: 'abc'"))
        );
    }
}

#[cfg(test)]
mod update_data {
    use super::*;

    #[test]
    fn create() {
        let cmds = vec![
            ControlCommand {
                actuator: Actuator::Mist,
                value: 1.0,
                duration: 10.0,
            },
            ControlCommand {
                actuator: Actuator::Lights,
                value: 0.5,
                duration: 10.0,
            },
        ];
        let update_data = create_update_data(&cmds);
        assert_eq!(
            update_data,
            ActuatorOverrideSet {
                updates: vec![
                    ActuatorOverride {
                        actuator: Actuator::Mist,
                        value: ActuatorValue::Bool(true),
                        duration_secs: 10,
                    },
                    ActuatorOverride {
                        actuator: Actuator::Lights,
                        value: ActuatorValue::Float(0.5),
                        duration_secs: 10,
                    }
                ],
            }
        );

        assert_eq!(
            serde_json::to_string(&update_data).unwrap(),
            "{\"updates\":[{\"actuator\":\"mist\",\"value\":true,\"duration_secs\":10},{\"actuator\":\"lights\",\"value\":0.5,\"duration_secs\":10}]}".to_string()
        );
    }
}

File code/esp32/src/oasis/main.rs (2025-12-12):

use embassy_executor::Spawner;
use embassy_futures::select;
use embassy_sync::blocking_mutex::raw::CriticalSectionRawMutex;
use embassy_sync::channel::Channel;
use embassy_time::{Duration, Timer};
use embedded_svc::http::{Headers, Method, client::Client as HttpClient};
use embedded_svc::io::{Read, Write};
use embedded_svc::utils::io;
use esp_idf_svc::fs::littlefs::Littlefs;
use esp_idf_svc::hal::task::block_on;
use esp_idf_svc::hal::{gpio, peripherals::Peripherals};
use esp_idf_svc::http::client::EspHttpConnection;
use esp_idf_svc::http::server::EspHttpServer;
use esp_idf_svc::io::vfs::MountedLittlefs;
use esp_idf_svc::mdns;
use esp_idf_svc::sntp;
use esp_idf_svc::timer::EspTaskTimerService;
use esp_idf_svc::wifi;
use esp_idf_svc::wifi::{AsyncWifi, EspWifi};
use esp_idf_svc::{eventloop::EspSystemEventLoop, nvs::EspDefaultNvsPartition};
use rand::Rng;
use std::fs::File;
use std::sync::{Arc, Mutex};
use std::time::Instant;
use terralib::cancel_context::CancelContext;
use terralib::config::{TerrariumConfig, TerrariumConfigUpdate, Update, WifiDetails};
use terralib::controller::{TerrariumController, spin_lock_mutex, terrarium_controller_main_loop};
use terralib::influxdb;
use terralib::terrarium::{get_terrarium_state, print_terrarium_info};
use terralib::types::{ActuatorOverrideSet, SensorValues, TerrariumState};
use terrarium::effects;
use terrarium::real_terrarium::RealTerrarium;

const INDEX_HTML: &str = include_str!("index.html");

const CONFIG_FILE_PATH: &str = "/oasisdata/config.json";

// Need lots of stack to parse JSON
const HTTP_SERVER_STACK_SIZE: usize = 12240;

// Max payload length
const MAX_REQUEST_LEN: usize = 512;

// this channel sends wifi config changes to the wifi management task, which
// asynchronously handles connecting and setting up access point mode.
static WIFI_DETAILS_CHANNEL: Channel<CriticalSectionRawMutex, Option<WifiDetails>, 1> =
    Channel::new();

#[embassy_executor::main]
async fn main(spawner: Spawner) {
    // It is necessary to call this function once. Otherwise some patches to the runtime
    // implemented by esp-idf-sys might not link properly. See https://github.com/esp-rs/esp-idf-template/issues/71
    esp_idf_svc::sys::link_patches();

    // Initialize logging to stdout.
    esp_idf_svc::log::EspLogger::initialize_default();

    log::info!("Oasis starting...");

    let peripherals = Peripherals::take().expect("Peripheral init should succeed");

    // setup status led
    let mut status_led =
        gpio::PinDriver::output(peripherals.pins.gpio7).expect("status_led should initialize");
    status_led
        .set_low()
        .expect("driving status led should work");

    // Mount /oasisdata partition and read config file.
    log::info!("Mounting littlefs on /oasisdata partition");
    let _mounted_littlefs = mount_data_partition().expect("Mounting data partition");
    let cfg = match read_config_file() {
        Ok(cfg) => {
            log::info!("Successfully read config file from nvs");
            cfg
        }
        Err(err) => {
            // TODO: differentiate between "not found" and other errors
            log::warn!("Unable to read config file from nvs: {err}");
            log::warn!("Using default config");
            let default = TerrariumConfig::new_with_reasonable_defaults();
            log::info!("Writing default config file to flash memory...");
            write_config_file(&default).expect("Saving config file should succeed");
            default
        }
    };

    let terrarium = match RealTerrarium::new(
        peripherals.ledc,
        peripherals.pins.gpio0,
        peripherals.pins.gpio1,
        peripherals.pins.gpio4,
        peripherals.pins.gpio3,
        peripherals.pins.gpio10,
        peripherals.i2c0,
        peripherals.temp_sensor,
    ) {
        Ok(t) => t,
        Err(err) => {
            panic!("Failed to initialize terrarium: {err}");
        }
    };

    let sys_loop = EspSystemEventLoop::take().expect("EspSystemEventLoop should initialize");
    let timer_service = EspTaskTimerService::new().expect("EspTaskTimerService should initialize");
    // note: the nvs partition is used to store wifi calibration data
    let nvs = EspDefaultNvsPartition::take().expect("EspDefaultNvsPartition should initialize");
    let wifi = Arc::new(Mutex::new(
        AsyncWifi::wrap(
            EspWifi::new(peripherals.modem, sys_loop.clone(), Some(nvs))
                .expect("EspWifi should initialize"),
            sys_loop,
            timer_service,
        )
        .expect("AsyncWifi should initialize"),
    ));

    let hostname = cfg.name.clone().unwrap_or("oasis".to_string());
    let cfg_wifi_details = cfg.wifi.clone();

    let controller = Arc::new(Mutex::new(TerrariumController::new(
        Arc::new(Mutex::new(terrarium)),
        cfg,
    )));

    // Initialize mdns service to broadcast the terrarium's hostname on the network.
    let mdns = Arc::new(Mutex::new(
        mdns::EspMdns::take().expect("EspMdns service should initialize"),
    ));
    {
        let mut mdns = mdns.lock().unwrap();
        mdns.set_hostname(hostname.as_str())
            .expect("Setting mdns hostname should succeed");
        mdns.add_service(
            /*instance_name*/ None,
            /*service_type*/
            "_oasis_terrarium",
            /*proto*/
            "_tcp",
            /*port*/ 80,
            /*txt*/ &[],
        )
        .expect("mdns service registration should succeed");
    }
    log::info!("Setup mdns broadcast for '{}'", hostname);

    // Initialize SNTP service to determine current time from the ntp servers on
    // the internet.
    let _sntp = sntp::EspSntp::new_default().expect("SNTP Service should initialize");
    log::info!("SNTP initialized");

    // Sleep for a bit to allow ntp to sync and get our system time accurate.
    // TODO: this makes startup significantly slower and probably isn't necessary.
    Timer::after(Duration::from_secs(5)).await;

    // Setup http server
    let server_configuration = esp_idf_svc::http::server::Configuration {
        stack_size: HTTP_SERVER_STACK_SIZE,
        ..Default::default()
    };
    let mut http_server =
        EspHttpServer::new(&server_configuration).expect("Http server should initialize");

    // The "/" route returns the main html ui page
    http_server
        .fn_handler("/", Method::Get, |req| {
            req.into_ok_response()?
                .write_all(INDEX_HTML.as_bytes())
                .map(|_| ())
        })
        .expect("Http handler registration should succeed");

    // The "/control" route accepts POST requests that specify values to set the
    // lights, fan, and mister to.
    let ctlref1 = controller.clone();
    http_server
        .fn_handler::<anyhow::Error, _>("/control", Method::Post, move |mut req| {
            let len = req.content_len().unwrap_or(0) as usize;
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

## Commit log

2025-05-31 website: fix a couple todos
2025-05-31 improve gitignore for kicad files
2025-06-02 website: add download links for 3d-printable models
2025-06-12 print out wifi connection status every 2 minutes
2025-06-15 use enum instead of strings to specify actuators
2025-06-19 esp32 code: implement wifi connection retry logic
2025-06-24 cleanup pcb/main/layout.py
2025-06-24 add dimensions to readme and landing page
2025-06-27 pcb: mark debug header as "do not place" and add a part number for i2c header
    [pcb.kicad_pcb, pcb.kicad_sch]
2025-06-28 pcb: update part # for esp32
    [pcb.kicad_pcb, pcb.kicad_sch]
2025-07-09 website: move "PCB Order History" section after "PCB Ordering Guide"
2025-07-09 code: improve error-handling in influxdb code
    [main.rs]
2025-07-11 github actions: kicad hack to fix ci
2025-12-12 don't print out config at startup
    I don't understand why, but on one of the terrariums, this is causing a crash loop with a message about a 'guru meditation error'. the other four terrariums don't have this issue
    [main.rs]
2026-11-12 nix: fix esp32 firmware builds in the dev shell
    - pin rust nightly to 2026-02-11. Newer nightlies' std fails to build
    for riscv32imc-esp-espidf (no field `st_atime` on `libc::stat`).
    - set LIBCLANG_PATH so esp-idf-sys's bindgen can find libclang.
2026-11-12 ci: pin rust nightly to 2026-02-11
    CI installed the latest nightly, whose std fails to build for
    riscv32imc-esp-espidf (no field `st_atime` on `libc::stat`). Pin it to
    match flake.nix, including in code/esp32/rust-toolchain.toml, which
    rustup uses over the default toolchain.
2026-11-12 ci: run code workflow on ubuntu-24.04
    ubuntu-latest is now ubuntu-26.04, whose libclang makes esp-idf-sys's
    bindgen generate spi_transaction_t bindings that esp-idf-hal doesn't
    compile against. Pin to the image the workflow last passed on.
